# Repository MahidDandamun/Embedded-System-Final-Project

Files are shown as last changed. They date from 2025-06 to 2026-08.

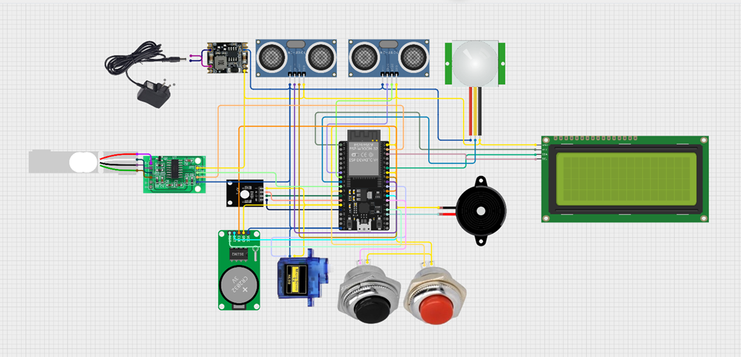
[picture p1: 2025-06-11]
docs/images/interfacing-diagram.png

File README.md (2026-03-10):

# Automated Pet Feeder System

An open-source, IoT-enabled automated pet feeder built with ESP32. Schedule feedings, monitor your pet's eating habits in real-time, and control everything from your phone.

<!-- ![Pet Feeder Hero](docs/images/hero.png) -->

## Features

- **Scheduled Auto-Feeding** — 4 configurable daily feeding times
- **Manual Feed** — Physical button or remote trigger from mobile app
- **Food Level Monitoring** — Ultrasonic sensor detects container level (FULL / HALF / EMPTY)
- **Bowl Weight Tracking** — HX711 load cell measures food in the bowl
- **Pet Detection** — PIR motion sensor detects animal presence
- **Mobile App Control** — React Native app connects via Bluetooth (BLE)
- **Cloud Telemetry** — Azure IoT Hub (MQTT) + REST API for data logging
- **Web Flasher** — Flash firmware from your browser via USB — no IDE needed
- **Status Display** — 16x2 LCD + RGB LED + buzzer feedback
- **Safety Limits** — Daily max (200g), minimum interval (5 min), bowl-full detection

## Repository Structure

```
├── firmware/               # ESP32 firmware (PlatformIO / C++)
│   ├── include/            #   Header files + config
│   ├── src/                #   Source files
│   ├── test/               #   Calibration test
│   └── platformio.ini
├── PCB/                    # KiCad PCB design for breakout board
├── 3D-MODEL/               # Fusion 360 housing + component mounts
├── docs/                   # Specs for mobile app & web flasher
│   ├── MOBILE_APP_SPEC.md  #   React Native mobile app spec
│   └── WEB_FLASHER_SPEC.md #   Next.js web flasher spec
├── .agents/                # AI agent rules, workflows, context
└── README.md               # You are here
```

### Companion Repositories (Separate)

| Repo | Tech Stack | Purpose |
|---|---|---|
| `petfeeder-mobile` | React Native (Expo) + TypeScript | Mobile app — BLE control, dashboard, history |
| `petfeeder-web` | Next.js + Web Serial API | Browser-based firmware flasher & calibration |

## Hardware Requirements

| Component | Model | Qty |
|---|---|-----|
| Microcontroller | ESP32 DevKit C | 1 |
| Ultrasonic Sensor | HC-SR04 | 1 |
| Load Cell + Amplifier | 5kg load cell + HX711 | 1 |
| PIR Motion Sensor | Generic | 1 |
| Servo Motor | SG90 or MG90S | 1 |
| LCD Display | 16x2 I2C (address 0x27) | 1 |
| RTC Module | DS1302 | 1 |
| RGB LED | Common cathode | 1 |
| Active Buzzer | 5V | 1 |
| Push Buttons | IP65 12mm momentary (x2) | 2 |
| Power Supply | 5V 2A, 5.5x2.1mm barrel jack | 1 |
| Rocker Switch | SPST | 1 |
| Custom PCB | See `PCB/` directory | 1 |
| 3D-Printed Housing | See `3D-MODEL/` directory | 1 |

## Quick Start

### 1. Clone

```bash
git clone https://github.com/MahidDandamun/Embedded-System-Final-Project.git
cd Embedded-System-Final-Project
```

### 2. Configure Secrets

```bash
cd firmware
cp include/secrets.h.template include/secrets.h
```

Edit `firmware/include/secrets.h` with your credentials:

```c
#define ENV_WIFI_SSID       "YourWiFi"
#define ENV_WIFI_PASSWORD   "YourPassword"
#define ENV_MQTT_SERVER     "your-hub.azure-devices.net"
#define ENV_MQTT_PORT       8883
#define ENV_DEVICE_ID       "petfeeder"
#define ENV_SAS_TOKEN       "SharedAccessSignature sr=..."
#define ENV_MQTT_USERNAME   "your-hub.azure-devices.net/petfeeder/?api-version=2021-04-12"
#define ENV_DATABASE_ENDPOINT "https://your-api.azurewebsites.net/api/devices/status"
```

> **Never commit `secrets.h`** — it's in `.gitignore`.

### 3. Build & Flash

```bash
# Install PlatformIO CLI
pip install platformio

# Build
pio run

# Upload to ESP32
pio run -t upload

# Monitor serial output
pio device monitor
```

### 4. Calibrate Load Cell

```bash
# Upload calibration firmware
pio test -e esp32dev -f test_calibration
```

Follow the serial prompts to find your `CALIBRATION_FACTOR`, then update it in `firmware/include/config.h`.

### 5. Assemble Hardware

1. Print the housing from `3D-MODEL/` (see [3D-MODEL/README.md](3D-MODEL/README.md))
2. Solder or order the PCB from `PCB/` (see [PCB/README.md](PCB/README.md))
3. Wire everything per the [pin mapping](firmware/README.md#pin-mapping-pcb-v2)
4. Power on and verify via serial monitor

## Architecture

```
┌─────────────┐     BLE      ┌─────────────┐
│  Mobile App │◄────────────►│    ESP32     │
│ (React Native)             │  Firmware    │
└─────────────┘              │             │
                             │  Sensors:    │
┌─────────────┐    MQTT      │  - Ultrasonic│
│  Azure IoT  │◄────────────►│  - Load Cell │
│    Hub      │              │  - PIR       │
└──────┬──────┘              │  - RTC       │
       │                     │             │
       │ REST                │  Actuators:  │
       ▼                     │  - Servo     │
┌─────────────┐              │  - LCD       │
│  Backend DB │              │  - RGB LED   │
│  (REST API) │              │  - Buzzer    │
└─────────────┘              └──────┬───────┘
                                    │ USB
┌─────────────┐    Web Serial      │
│  Web Flasher│◄───────────────────┘
│  (Next.js)  │
└─────────────┘
```

## Mobile App

The companion mobile app (separate repo) provides:

- **Dashboard** — Real-time sensor data, feeding status, pet detection
- **Feeding History** — Charts and timeline of all feeding events
- **Schedule Control** — Edit feeding times and portion sizes
- **BLE Connection** — Direct Bluetooth communication with the feeder
- **Push Notifications** — Low food alerts, missed feeding warnings

**Tech Stack:** React Native (Expo) + TypeScript + Zustand + react-native-ble-plx

See full spec: [docs/MOBILE_APP_SPEC.md](docs/MOBILE_APP_SPEC.md)

## Web Flasher

A browser-based tool to flash firmware and calibrate sensors — no IDE installation required:

1. Connect ESP32 via USB-C
2. Enter WiFi/cloud credentials in the web form
3. Click "Flash" — firmware uploads directly from Chrome
4. Run guided sensor calibration

**Tech Stack:** Next.js + TypeScript + Web Serial API + esptool-js

See full spec: [docs/WEB_FLASHER_SPEC.md](docs/WEB_FLASHER_SPEC.md)

## Pin Mapping

| Function | GPIO | Notes |
|---|---|---|
| Power Relay | 27 | System power control |
| Button 1 (Refill) | 15 | INPUT_PULLUP |
| Button 2 (Feed) | 0 | INPUT_PULLUP |
| Ultrasonic Trig | 32 | |
| Ultrasonic Echo | 33 | |
| PIR Sensor | 25 | |
| HX711 DOUT | 5 | |
| HX711 SCK | 23 | |
| RGB Red | 13 | |
| RGB Green | 12 | |
| RGB Blue | 14 | |
| Buzzer | 26 | Active buzzer |
| Servo | 4 | SG90/MG90S |
| RTC IO | 16 | DS1302 |
| RTC SCLK | 17 | DS1302 |
| RTC CE | 2 | DS1302 |

## Security Notes

- All credentials are stored in `secrets.h` which is **never committed** to git
- A `secrets.h.template` is provided as reference
- Azure SAS tokens should be rotated regularly
- For production: replace `setInsecure()` with proper TLS certificate pinning
- If you ever accidentally commit secrets: **rotate ALL credentials immediately**

### Regarding Credentials in Git History

The credentials found in older commits have been **revoked and are no longer valid**. The WiFi password, Azure SAS tokens, and API endpoints from the git history are all invalidated. Always generate your own fresh credentials.

## Contributing

1. Fork the repository
2. Create a feature branch (`git checkout -b feat/amazing-feature`)
3. Use conventional commits (`feat:`, `fix:`, `docs:`, `refactor:`)
4. Ensure no secrets are in your commits
5. Open a Pull Request

## License

This project is licensed under the [MIT License](LICENSE).

## Authors

- Irish Micole Cando
- Jelisha Bugnon
- Angela Corpuz
- Mahid Dandamun
- Miguel Alfonso Neri

---

> Built as a final project for Embedded Systems course. Designed to be open-source, educational, and production-ready.

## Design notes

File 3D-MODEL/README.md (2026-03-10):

# 3D Model — Pet Feeder Housing

This directory contains the complete 3D model files for the automated pet feeder enclosure.

## Files

| File | Description |
|---|---|
| `AUTOMATED PET FEEDER SYSTEM 3D MODEL.f3z` | Full Fusion 360 project (editable) |
| `PRAMS 2.0 v3.step` | Complete assembled housing (STEP) |
| `FINAL PROJ v5.step` | Final assembly with all components |
| `Pet bowls v1.step` | Food/water bowl models |
| `microservoAssembly v2.step` | Servo motor mount assembly |
| `ESP32-DevkitC32D v1.step` | ESP32 dev board model |
| `HC-SR04 (1) v1.step` | Ultrasonic sensor mount |
| `LCD WITH IIC v1.step` | LCD display bracket |
| `Led RGB for arduino v1.step` | RGB LED holder |
| `load sensor FHDA v1.step` | Load cell mount |
| `PIR Sensor (1) v1.step` | PIR motion sensor mount |
| `RTC DS1302 real time clock v1.step` | RTC module bracket |
| `DC Power Jack 5.5mm x 2.1mm v1.step` | Power jack cutout |
| `RockerSwitch v1.step` | Power switch mount |
| `STARELO 12mm Momentary Push Button...v1.step` | Button mount |

## Housing Assembly Guide

### What You Need

- 3D printer (FDM, PLA or PETG recommended)
- M3 screws and nuts
- Hot glue gun (for sensor mounts)
- Wire (22 AWG for internal wiring)

### Print Settings

| Parameter | Value |
|---|---|
| Material | PLA or PETG |
| Layer Height | 0.2mm |
| Infill | 20–30% |
| Supports | Yes (for overhangs) |
| Wall Thickness | 1.2mm (3 walls) |

### Assembly Steps

1. **Print all housing parts** — Use the STEP files to slice in your slicer software (Cura, PrusaSlicer, etc.)

2. **Install the load cell** — Mount the load cell under the bowl platform using M3 screws. Run wires through the channel to the electronics bay.

3. **Mount the servo** — Use `microservoAssembly v2.step` as reference. The servo controls the food gate. Secure with provided mounting holes.

4. **Install sensors**
   - **Ultrasonic (HC-SR04):** Mount at the top of the food container, pointing downward
   - **PIR Sensor:** Mount near the bowl at pet height
   - **RGB LED:** Install in the front-facing LED slot

5. **Install electronics**
   - **ESP32:** Snap into the bracket inside the electronics bay
   - **LCD Display:** Slide into the front-facing LCD slot
   - **RTC Module:** Mount near the ESP32
   - **Power Jack & Switch:** Install in the rear panel cutouts

6. **Wire everything** per the pin mapping in [firmware/README.md](../firmware/README.md)

7. **Close the housing** and secure with M3 screws

### System Preview

<!-- Add a screenshot of your 3D model here -->
<!-- ![Pet Feeder 3D Model](images/3d-model-preview.png) -->

> **TODO:** Add photos/screenshots of the assembled 3D model here.

### Tips

- Print the bowl platform in PETG for better food safety
- Use cable management clips inside the housing
- Leave access to the USB port for firmware updates
- The power jack hole fits a standard 5.5mm × 2.1mm barrel connector

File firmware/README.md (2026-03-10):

# Firmware — Automated Pet Feeder (ESP32)

PlatformIO-based firmware for the ESP32 pet feeder system.

## Features

- Scheduled auto-feeding (4 times/day, configurable)
- Manual feed via physical button or mobile app (BLE)
- Ultrasonic food-level sensing
- HX711 load cell for bowl weight
- PIR motion detection (animal presence)
- RGB LED + buzzer status feedback
- Azure IoT Hub telemetry via MQTT
- REST API push to backend database
- BLE interface for mobile app control & live status

## Quick Start

### 1. Install PlatformIO

```bash
pip install platformio
# or install the VS Code PlatformIO extension
```

### 2. Configure Secrets

```bash
cp include/secrets.h.template include/secrets.h
```

Edit `include/secrets.h` with your actual credentials:
- WiFi SSID & password
- Azure IoT Hub connection string
- Backend API endpoint

> **Never commit `secrets.h`** — it's listed in `.gitignore`.

### 3. Build & Upload

```bash
pio run                 # compile
pio run -t upload       # flash to ESP32
pio device monitor      # serial monitor (115200 baud)
```

### 4. Calibration

Run the calibration test to set your load cell factor:

```bash
pio test -e esp32dev -f test_calibration
```

Or upload `test/test_calibration.cpp` as the main sketch, follow the serial prompts, and note the factor. Update `CALIBRATION_FACTOR` in `include/config.h`.

## Pin Mapping (PCB v2)

| Function | GPIO |
|---|---|
| Power Relay | 27 |
| Button 1 | 15 |
| Button 2 | 0 |
| Ultrasonic Trig | 32 |
| Ultrasonic Echo | 33 |
| PIR Sensor | 25 |
| HX711 DOUT | 5 |
| HX711 SCK | 23 |
| RGB Red | 13 |
| RGB Green | 12 |
| RGB Blue | 14 |
| Buzzer | 26 |
| Servo | 4 |
| RTC IO | 16 |
| RTC SCLK | 17 |
| RTC CE | 2 |

## Architecture

```
firmware/
├── include/
│   ├── config.h              # All pin/timing/threshold config + structs
│   ├── secrets.h.template    # Template for credentials
│   ├── globals.h             # Extern declarations
│   ├── system_init.h
│   ├── sensor_manager.h
│   ├── feeding_control.h
│   ├── button_handler.h
│   ├── display_manager.h
│   ├── time_manager.h
│   ├── network_manager.h
│   ├── ble_manager.h         # BLE for mobile app
│   └── load_cell.h
├── src/
│   ├── main.cpp              # Setup + main loop
│   ├── globals.cpp
│   ├── system_init.cpp
│   ├── sensor_manager.cpp
│   ├── feeding_control.cpp
│   ├── button_handler.cpp
│   ├── display_manager.cpp
│   ├── time_manager.cpp
│   ├── network_manager.cpp   # MQTT + HTTP
│   ├── ble_manager.cpp       # BLE service
│   └── load_cell.cpp
├── test/
│   └── test_calibration.cpp  # Load cell calibration
└── platformio.ini
```

## BLE Protocol (for Mobile App)

| Characteristic | UUID | Direction | Format |
|---|---|---|---|
| Command | `beb5483e-...` | Write | `{"cmd":"feed"}` or `{"cmd":"refill"}` or `{"cmd":"tare"}` |
| Status | `a3c87500-...` | Notify | JSON with all sensor/state data |

The mobile app connects via BLE, sends commands, and receives real-time status updates every 2 seconds.

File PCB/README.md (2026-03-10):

# PCB — Pet Feeder Breakout Board

KiCad PCB design for the ESP32 pet feeder breakout/carrier board.

## Files

| File | Description |
|---|---|
| `FINAL PROJ.kicad_sch` | Schematic |
| `FINAL PROJ.kicad_pcb` | PCB layout |
| `FINAL PROJ.kicad_pro` | KiCad project |
| `FINAL PROJ.step` | 3D model of PCB |
| `freerouting.dsn` | Auto-routing export |
| `config.h` | Pin mapping reference (mirrors firmware config) |

## Features

- ESP32 DevKit C socket
- Breakout headers for all sensors (HC-SR04, PIR, HX711, DS1302)
- Servo connector (5V + signal)
- I2C header for LCD
- RGB LED + buzzer outputs
- 5V barrel jack power input with rocker switch
- Dual push-button inputs

## Opening the Design

1. Install [KiCad](https://www.kicad.org/) (v7+ recommended)
2. Open `FINAL PROJ.kicad_pro`
3. Schematic → `FINAL PROJ.kicad_sch`
4. PCB Layout → `FINAL PROJ.kicad_pcb`

## Manufacturing

Export Gerbers from KiCad and upload to your preferred PCB fab (JLCPCB, PCBWay, OSH Park, etc.).

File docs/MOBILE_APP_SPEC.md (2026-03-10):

# Mobile App — Pet Feeder Companion (Separate Repository)

> **Repository:** Create as `petfeeder-mobile` (separate repo)

## Tech Stack (Production-Grade, In-Demand)

| Layer | Technology | Why |
|---|---|-----|
| **Framework** | React Native + Expo (SDK 52+) | Cross-platform iOS/Android, massive ecosystem, most in-demand mobile framework |
| **Language** | TypeScript | Type safety, better DX, industry standard |
| **Navigation** | Expo Router (file-based) | Modern, Next.js-style routing for RN |
| **State Management** | Zustand | Lightweight, scalable, minimal boilerplate |
| **BLE Communication** | react-native-ble-plx | Best-maintained BLE library for React Native |
| **Cloud/API** | Azure IoT Hub SDK or REST | Match firmware's Azure backend |
| **Real-time** | Azure SignalR or WebSocket | Live dashboard updates |
| **Charts** | Victory Native or react-native-chart-kit | Historical data visualization |
| **UI Library** | Tamagui or NativeWind (Tailwind) | Production-level, performant styling |
| **Auth** | Clerk or Supabase Auth | Modern auth with social login |
| **Database** | Supabase (PostgreSQL) or Azure Cosmos DB | Historical data storage |
| **Push Notifications** | Expo Notifications | Feeding alerts, low-food warnings |

## Architecture

```
petfeeder-mobile/
├── app/                        # Expo Router screens
│   ├── (tabs)/
│   │   ├── index.tsx           # Dashboard (home)
│   │   ├── history.tsx         # Feeding history
│   │   ├── schedule.tsx        # Feeding schedule management
│   │   ├── settings.tsx        # Device & app settings
│   │   └── _layout.tsx         # Tab navigation layout
│   ├── device/
│   │   ├── connect.tsx         # BLE device scanning & pairing
│   │   ├── calibrate.tsx       # Load cell calibration wizard
│   │   └── [id].tsx            # Individual device detail
│   ├── auth/
│   │   ├── login.tsx
│   │   └── register.tsx
│   └── _layout.tsx             # Root layout
├── components/
│   ├── ui/                     # Reusable UI components
│   │   ├── Card.tsx
│   │   ├── Button.tsx
│   │   ├── Badge.tsx
│   │   └── Chart.tsx
│   ├── dashboard/
│   │   ├── FoodLevelGauge.tsx
│   │   ├── BowlWeightCard.tsx
│   │   ├── FeedingStatusCard.tsx
│   │   ├── MotionIndicator.tsx
│   │   └── QuickFeedButton.tsx
│   └── device/
│       ├── BLEScanner.tsx
│       └── DeviceCard.tsx
├── hooks/
│   ├── useBLE.ts               # BLE connection management
│   ├── useDevice.ts            # Device state from BLE/cloud
│   ├── useFeedingHistory.ts    # Historical data queries
│   └── useRealTimeData.ts      # Live sensor data
├── stores/
│   ├── deviceStore.ts          # Zustand store for device state
│   ├── authStore.ts
│   └── settingsStore.ts
├── services/
│   ├── ble/
│   │   ├── bleService.ts       # BLE connection & communication
│   │   ├── bleProtocol.ts      # Command/status JSON protocol
│   │   └── bleConstants.ts     # UUIDs matching firmware
│   ├── api/
│   │   ├── apiClient.ts        # REST API client
│   │   ├── feedingApi.ts
│   │   └── deviceApi.ts
│   └── notifications/
│       └── pushService.ts
├── utils/
│   ├── formatters.ts
│   └── constants.ts
├── types/
│   ├── device.ts
│   ├── feeding.ts
│   └── sensor.ts
├── assets/
├── app.json
├── package.json
└── tsconfig.json
```

## Key Screens

### 1. Dashboard
- **Real-time food level** — gauge/progress bar (FULL/HALF/EMPTY)
- **Bowl weight** — live grams display
- **Next feeding** — countdown timer
- **Pet detection** — motion indicator
- **Quick Feed** — one-tap manual dispense
- **Connection status** — BLE/WiFi/MQTT indicators
- **Daily summary** — grams dispensed today

### 2. Feeding History
- **Timeline view** — all feeding events (auto + manual)
- **Daily/weekly/monthly charts** — consumption trends
- **Export** — CSV download for vet records
- **Filters** — by date range, feeding type

### 3. Schedule Management
- **Edit feeding times** — add/remove/modify schedule
- **Portion size** — adjust grams per feeding
- **Daily limit** — set maximum daily grams
- **Toggle auto-feeding** — enable/disable

### 4. Device Settings
- **BLE pairing** — scan and connect to feeder
- **WiFi configuration** — update WiFi credentials via BLE
- **Calibration** — guided load cell calibration
- **Firmware info** — version, uptime, diagnostics
- **Notifications** — configure alerts (low food, missed feeding, etc.)

## BLE Protocol

The app communicates with ESP32 via BLE using JSON:

**Send commands:**
```json
{"cmd": "feed"}
{"cmd": "refill"}
{"cmd": "tare"}
{"cmd": "schedule", "times": [480, 720, 1080, 1320]}
{"cmd": "wifi", "ssid": "...", "password": "..."}
```

**Receive status (every 2s via BLE notify):**
```json
{
  "food": "FULL",
  "bowl": "PARTIAL",
  "weight": 85.5,
  "distance": 5.2,
  "dispensing": false,
  "refill": false,
  "dailyFood": 75.0,
  "motion": true,
  "status": "Ready to feed",
  "wifi": true,
  "mqtt": true,
  "time": "14:30:00",
  "nextFeed": "18:00:00"
}
```

## Getting Started

```bash
# Create the repo
npx create-expo-app petfeeder-mobile --template tabs
cd petfeeder-mobile

# Install core dependencies
npx expo install react-native-ble-plx
npm install zustand
npm install @tamagui/core tamagui
npm install victory-native

# Development
npx expo start

# Build
eas build --platform all
```

## UI/UX Guidelines

- **Design System:** Use consistent spacing (4px grid), rounded corners, soft shadows
- **Colors:** Green (full), Blue (half), Red (empty), Purple (dispensing), Yellow (refill)
- **Dark Mode:** Support system theme preference
- **Haptics:** Tap feedback on buttons
- **Animations:** Smooth transitions for gauge values, card reveals
- **Accessibility:** Screen reader labels, minimum touch targets (44×44pt)
- **Offline Mode:** Cache last-known device state when BLE disconnects

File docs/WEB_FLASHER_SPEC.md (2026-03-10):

# Web Flasher & Calibration Tool (Separate Repository)

> **Repository:** Create as `petfeeder-web` (separate repo)

## Overview

A web application that lets users:
1. **Select a project/firmware** from available embedded firmware variants
2. **Flash firmware** directly to their ESP32 via USB (Web Serial API)
3. **Calibrate sensors** (load cell, ultrasonic) through a guided wizard
4. **Configure WiFi/cloud credentials** before flashing

No desktop software required — works entirely in the browser via USB-C/USB connection.

## Tech Stack

| Layer | Technology | Why |
|---|---|-----|
| **Framework** | Next.js 15 (App Router) | SEO, SSR, best React framework |
| **Language** | TypeScript | Type safety |
| **Styling** | Tailwind CSS + shadcn/ui | Production-level components |
| **Firmware Flashing** | Web Serial API + esptool-js | Flash ESP32 from browser |
| **State** | Zustand | Simple, scalable |
| **Database** | Supabase or Vercel Postgres | Store firmware binaries, user configs |
| **Auth** | Clerk or NextAuth.js | User accounts |
| **Hosting** | Vercel | Zero-config deployment |

## Architecture

```
petfeeder-web/
├── app/
│   ├── page.tsx                  # Landing page
│   ├── projects/
│   │   ├── page.tsx              # Browse available firmware projects
│   │   └── [slug]/
│   │       ├── page.tsx          # Project detail + flash button
│   │       ├── flash/
│   │       │   └── page.tsx      # Flashing wizard
│   │       └── calibrate/
│   │           └── page.tsx      # Calibration wizard
│   ├── dashboard/
│   │   └── page.tsx              # User's devices & history
│   └── layout.tsx
├── components/
│   ├── ui/                       # shadcn components
│   ├── flash/
│   │   ├── SerialConnect.tsx     # USB connection prompt
│   │   ├── FlashProgress.tsx     # Progress bar during flash
│   │   ├── FirmwareSelector.tsx  # Choose firmware variant
│   │   └── CredentialForm.tsx    # WiFi/API config before flash
│   ├── calibrate/
│   │   ├── LoadCellWizard.tsx    # Step-by-step calibration
│   │   ├── UltrasonicWizard.tsx
│   │   └── SerialMonitor.tsx     # Live serial output
│   └── projects/
│       ├── ProjectCard.tsx
│       └── ProjectGrid.tsx
├── lib/
│   ├── serial/
│   │   ├── serialService.ts      # Web Serial API wrapper
│   │   ├── espFlasher.ts         # esptool-js integration
│   │   └── serialMonitor.ts      # Read serial output
│   ├── firmware/
│   │   ├── firmwareBuilder.ts    # Inject credentials into firmware
│   │   └── firmwareStore.ts      # Fetch firmware binaries
│   └── supabase/
│       └── client.ts
├── public/
│   └── firmware/                  # Pre-compiled firmware binaries
│       ├── petfeeder-v2.0.0.bin
│       └── manifest.json
├── package.json
├── next.config.ts
└── tailwind.config.ts
```

## User Flow

### Flash Firmware
```
1. User visits /projects and selects "Pet Feeder"
2. Clicks "Flash to Device"
3. Enters WiFi SSID, password, Azure IoT credentials
4. Connects ESP32 via USB-C cable
5. Browser prompts for serial port access
6. Credentials are injected into firmware binary
7. Firmware is flashed to ESP32 (progress bar)
8. Device reboots and connects to WiFi
9. Success screen with next steps
```

### Calibrate Sensors
```
1. User visits /projects/pet-feeder/calibrate
2. Connects ESP32 via USB
3. Guided wizard:
   a. "Remove all weight from scale" → Tare
   b. "Place 100g weight" → Read
   c. Shows calibration factor
   d. "Verify: place known weight" → Confirm
4. Factor is saved to device EEPROM
```

## Web Serial API Requirements

- **Browser:** Chrome 89+, Edge 89+, Opera 76+ (no Firefox/Safari)
- **Connection:** USB-C or USB-Micro to ESP32
- **Baud Rate:** 115200
- **Protocol:** The web app sends serial commands and reads responses

### Serial Commands (Calibration Mode)
```
> TARE
< OK:TARED
> CALIBRATE:100.0
< OK:FACTOR:49400
> VERIFY
< OK:WEIGHT:99.8
> SAVE
< OK:SAVED
```

## Key Features

### Firmware Project Browser
- Grid of available firmware projects (Pet Feeder, future projects)
- Version history
- Hardware requirements list
- Difficulty rating

### Flash Wizard
- Step-by-step with clear instructions
- Auto-detect ESP32 board type
- Credential injection (compile-time or runtime EEPROM write)
- Progress bar with stage labels (Connecting → Erasing → Writing → Verifying)
- Error recovery (retry, reset instructions)

### Calibration Tool
- Live serial monitor output
- Interactive guided steps with illustrations
- Save calibration to device
- Export calibration report

### Dashboard (Logged-in Users)
- List of flashed devices
- Firmware update notifications
- Configuration backup/restore

## Getting Started

```bash
# Create the repo
npx create-next-app@latest petfeeder-web --typescript --tailwind --app
cd petfeeder-web

# Install dependencies
npm install esptool-js
npx shadcn@latest init
npm install zustand

# Development
npm run dev

# Deploy
vercel deploy
```

## Browser Compatibility Note

Web Serial API is only available in Chromium-based browsers. Display a compatibility notice for unsupported browsers with a link to Chrome download.

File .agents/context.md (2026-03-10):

# Agent Context — Project Overview

## What Is This?

An open-source **Automated Pet Feeder System** built as an embedded systems project. It consists of multiple repositories and components:

### This Repository (Main)
- **firmware/** — ESP32 C++ firmware (PlatformIO)
- **PCB/** — KiCad breakout board design
- **3D-MODEL/** — Fusion 360 housing and component mounts
- **docs/** — Additional documentation

### Companion Repositories (Separate)
- **petfeeder-mobile** — React Native (Expo) mobile app
- **petfeeder-web** — Next.js web flasher + calibration tool

## Hardware Components

| Component | Model | Purpose |
|---|---|---|
| Microcontroller | ESP32 DevKit C | Main controller, WiFi + BLE |
| Ultrasonic Sensor | HC-SR04 | Food level detection |
| Load Cell + HX711 | Generic 5kg | Bowl weight measurement |
| PIR Sensor | Generic | Animal presence detection |
| Servo Motor | SG90 / MG90S | Food gate actuator |
| LCD Display | 16×2 I2C (0x27) | Status display |
| RTC Module | DS1302 | Timekeeping |
| RGB LED | Common cathode | Status indicator |
| Buzzer | Active | Audio feedback |
| Push Buttons | x2 (IP65) | Refill mode + Manual feed |
| Power | 5V 2A barrel jack | System power |

## Communication Channels

1. **BLE** — Mobile app ↔ ESP32 (local, low-latency)
2. **MQTT** — ESP32 → Azure IoT Hub (telemetry + remote commands)
3. **HTTP** — ESP32 → REST API backend (database sync)
4. **Web Serial** — PC ↔ ESP32 (firmware flashing via web app)

## Feeding Schedule

Default: 08:00, 12:00, 18:00, 22:00 — configurable in `config.h`.

- 25g per feeding
- 200g daily max
- 5-minute minimum interval between feedings
- Bowl-full detection prevents over-feeding

## Team

- Irish Micole Cando
- Jelisha Bugnon
- Angela Corpuz
- Mahid Dandamun
- Miguel Alfonso Neri

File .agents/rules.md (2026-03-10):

# Agent Rules — Pet Feeder Project

## Project Context

This is an open-source automated pet feeder system built with:

- **Hardware:** ESP32 (PlatformIO/Arduino framework)
- **Cloud:** Azure IoT Hub (MQTT) + REST API backend
- **Mobile App:** React Native (Expo) — separate repository
- **Web Flasher:** Next.js + Web Serial API — separate repository
- **PCB:** KiCad
- **3D Model:** Fusion 360

## Coding Standards

### C++ (Firmware)

- Use `const char*` over `String` for fixed strings to reduce heap fragmentation
- Use `char[]` in structs, not `String`
- All timing via `millis()` — never use blocking `delay()` in main loop
- Prefix private/static helpers with `static`
- Use `snprintf` over `sprintf` — always pass buffer size
- Use `strncpy` over `strcpy` — always pass size
- No dynamic memory allocation in loop
- Keep ISRs minimal
- Follow the existing module pattern: each feature in its own `.h` + `.cpp` pair

### Secrets & Security

- **NEVER** commit `secrets.h`, `.env`, API keys, tokens, or passwords
- Always load credentials from `secrets.h` which is gitignored
- Use `secrets.h.template` as the checked-in reference
- For production: use proper TLS certificate pinning (not `setInsecure()`)

### Git

- Conventional commits: `feat:`, `fix:`, `refactor:`, `docs:`, `chore:`
- One logical change per commit
- Do not commit build artifacts (`.pio/`, `build/`, `node_modules/`)
- Do not commit IDE configs (`.vscode/` settings that are user-specific)

## Architecture Decisions

1. **BLE for mobile app** — Low-latency local control without requiring WiFi. The mobile app connects directly to the ESP32 over BLE.
2. **MQTT for cloud** — Reliable pub/sub for telemetry and remote commands via Azure IoT Hub.
3. **HTTP POST for DB** — Simple REST fallback for database status updates.
4. **DS1302 RTC** — Keeps feeding schedule accurate even without WiFi.
5. **Modular firmware** — Each subsystem (sensors, feeding, display, network, BLE) is isolated in its own module for testability and readability.

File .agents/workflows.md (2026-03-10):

# Agent Workflows

## Firmware Development Workflow

```
1. Edit code in firmware/src/ and firmware/include/
2. Build: pio run
3. Upload: pio run -t upload
4. Monitor: pio device monitor
5. Test: pio test
```

## Adding a New Sensor

```
1. Create include/new_sensor.h with function declarations
2. Create src/new_sensor.cpp with implementation
3. Add extern globals to include/globals.h if needed
4. Add pin definitions to include/config.h
5. Call init from system_init.cpp
6. Call handler from main.cpp loop
7. Add data fields to SensorData struct in config.h
8. Update BLE status payload in ble_manager.cpp
9. Update MQTT telemetry payload in network_manager.cpp
```

## Adding a New BLE Command

```
1. Add command handler in ble_manager.cpp CmdCallbacks::onWrite()
2. Send JSON from mobile app: {"cmd": "your_command", ...params}
3. Document in firmware/README.md BLE Protocol table
```

## Adding a New MQTT Direct Method

```
1. Add method handler in network_manager.cpp handleDirectMethod()
2. Register in Azure IoT Hub portal
3. Send response on "$iothub/methods/res/{status}/?$rid={rid}"
```

## Calibration Workflow

```
1. Upload test/test_calibration.cpp
2. Follow serial prompts to tare and place known weight
3. Note the CALIBRATION_FACTOR
4. Update CALIBRATION_FACTOR in include/config.h
5. Re-upload main firmware
```

## Secrets Management

```
1. cp include/secrets.h.template include/secrets.h
2. Edit secrets.h with real values
3. NEVER commit secrets.h
4. If accidentally committed: rotate ALL credentials immediately
```

## Release Workflow

```
1. Update FIRMWARE_VERSION in config.h
2. Test all features (feeding, BLE, MQTT, sensors)
3. Run calibration verification
4. Commit with: feat: release v{version}
5. Tag: git tag v{version}
6. Push: git push --tags
```

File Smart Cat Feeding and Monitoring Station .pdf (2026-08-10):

Republic of the Philippines
Polytechnic | University | of | the
Philippines
College of Engineering
Computer Engineering Department

## Embedded Systems

# Smart Cat Feeding and Monitoring Station

### Introduction

a. The Team
BSCOE 4-2 | Group 5
Name | Role
Bugnon, Jelisha Ruth B. | Prototype Designer
Cando, Irish Micole T. | Website Developer
Corpuz, Angela E. | Prototype Designer
Dandamun, Mahid L. | Hardware Engineer
Neri, Miguel Alfonso B. | Prototype Designer
b. Overview of the system

In modern urban lifestyles, many cat owners lead busy schedules that require them to be away from home for extended periods, whether due to work commitments, frequent travel, or other obligations. While cats are often considered low-maintenance pets compared to dogs, they still require regular care, particularly in terms of feeding and health monitoring. The absence of a reliable and consistent feeding routine can negatively affect a cat’s well-being, especially when owners are unable to be present at scheduled mealtimes.

Irregular feeding patterns may lead to a variety of health issues in cats, such as obesity, malnutrition, or gastrointestinal discomfort. These issues are often exacerbated when there is no one available to monitor the pet's behavior or appetite changes, which can be early signs of underlying medical conditions (Gunn-Moore, 2005). Moreover, prolonged solitude without supervision can result in stress and behavioral problems for the cat. For owners, this lack of oversight often results in anxiety and uncertainty about their pet’s condition while they are away.

The Smart Cat Feeding and Monitoring Station is an embedded system designed to provide convenience and assurance for cat owners who are frequently away from home. It automates feeding schedules, monitors food levels, and detects cat presence and feeding behavior. With a combination of sensors, actuators, and a microcontroller, the system ensures timely feeding while tracking essential metrics through a web-based dashboard. This setup not only promotes better cat care but also allows owners to monitor and respond remotely.

c. Objectives and goals of the system

The main objectives of the Smart Cat Feeding and Monitoring Station are as follows:

- To automate cat feeding on a schedule using a servo-controlled dispenser.
- To monitor food intake and cat presence using weight sensors and motion detectors.
- To alert the owner when the cat is not eating, food levels are low, or other abnormal activities are detected.
- To log and display feeding data and cat presence via an intuitive web dashboard.
- To provide manual feed control, both physically through push buttons and remotely through the dashboard.
d. Features of the system

The following are the features implemented into the system, ensuring full delivery of the objectives mentioned beforehand:

- Feeding Detection: Measures weight before and after feeding to log intake.
- Cat Presence Monitoring: Uses PIR sensor to track cat approach and interaction time.
- Real-Time Alerts: Buzzer, RGB LED, and web notifications for low food or missed feeding.
- Web Dashboard Integration: Displays feeding logs, activity data, and manual control options.
- LCD Display: Provides on-device information including food weight and system alerts.
- Scheduled and Manual Feeding: Automated feeding based on real-time clock, with options for physical or remote manual feed override.

### Hardware Requirements

a. List of necessary components needed/used. Discuss briefly each component and its purpose.
Quantity | Component Name | Purpose
1 | ESP32 WROOM 32D (38pin) | Main microcontroller with Wi-Fi/Bluetooth for connectivity and logic control
1 | Ultrasonic Sensor (HC-SR04) | Detects the distance of food level
1 | PCB for power and modules | For power distribution and connection of components
1 | PIR SENSOR | Detects the presence of animal via heat
1 | Load Cell + HX711 Amplifier | Measures the weight of the food bowl to detect feeding
1 | Servo Motor | Dispenses food automatically

1 | Real-Time Clock (RTC) Module | Keeps accurate time for feeding history
1 | Buzzer | Gives sound alerts for low food
1 | RGB LED | Visual indicator for low food
1 | LCD | Displays real-time information such as current food weight/percentage, feeding status, alerts
2 | Momentary Push Button | Buttons for dispensing and refilling of the food tank
1 | Food Bowl | Container where the cat eats; used in conjunction with the load cell to monitor food intake
1 | Food Container | Storage container for cat food; supplies food to the dispensing mechanism
— | Plywood | Used as the primary material for building the casing and structural frame

### Software Requirements

a. Libraries required for the project (if any)
- marcoschwartz/LiquidCrystal_I2C@^1.1.4
- bogde/HX711@^0.7.5
- knolleary/PubSubClient@^2.8
- bblanchon/ArduinoJson@^6.21.3
- madhephaestus/ESP32Servo@^0.13.0
- makuna/RTC@^2.5.0
b. Source Code (C++ program). Please provide a google link of the sketch

GitHub Repository Links for the source codes used in developing the system:

1. Hardware Code: https://github.com/MahidDandamun/Embedded-System-Final-Project.git

### 2. Website Code (Front End): https://github.com/irishmicoletcando/pet-feeder-frontend.git

### 3. Website Code (Back End): https://github.com/irishmicoletcando/pet-feeder-backend.git

### 4. Actual Website: https://pet-feeder-ruddy.vercel.app

### System Design and settings

a. System Architecture/Interfacing diagram of the system

Schematic Diagram

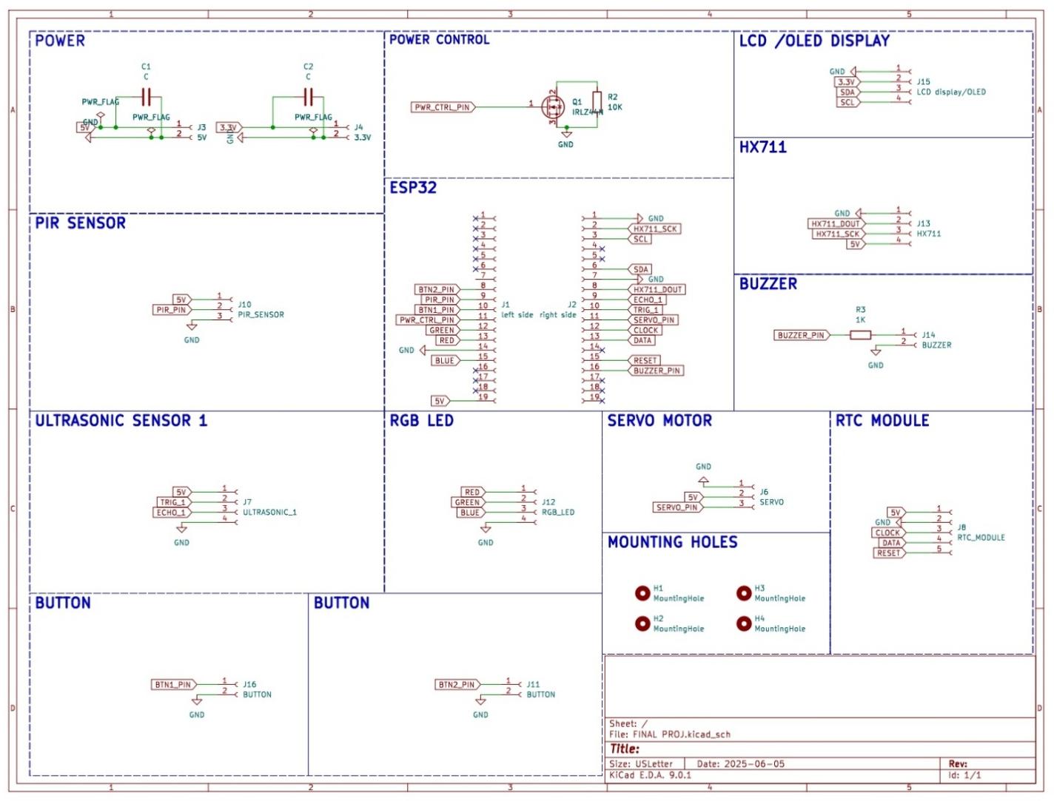
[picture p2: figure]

Interface Diagram

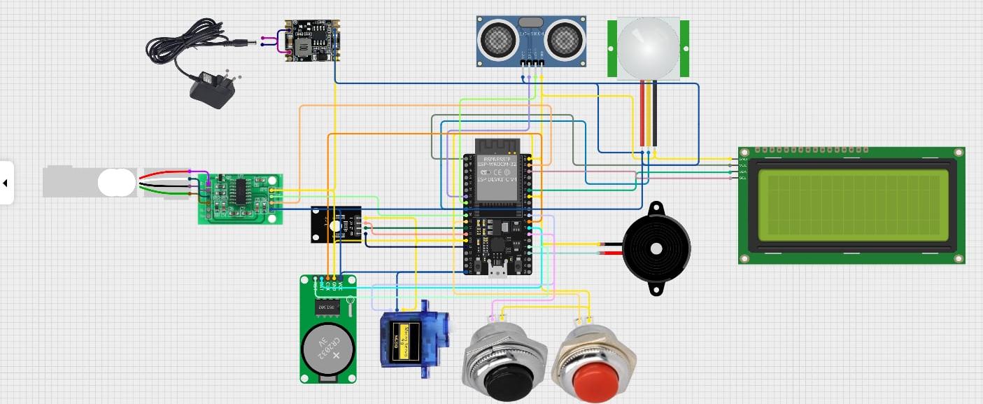
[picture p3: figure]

Current Consumption

Component | Current (mA)
Ultrasonic Sensor | 6
Servo Motor | 500
ESP32 (WiFi) | 400
RGB Module | 20
LCD I2C | 3
PIR Sensor | 3
RTC Module | 0.3
HX711 | 1.6
Buzzer | 30
Buttons (est.) | 1
Total | 964.9

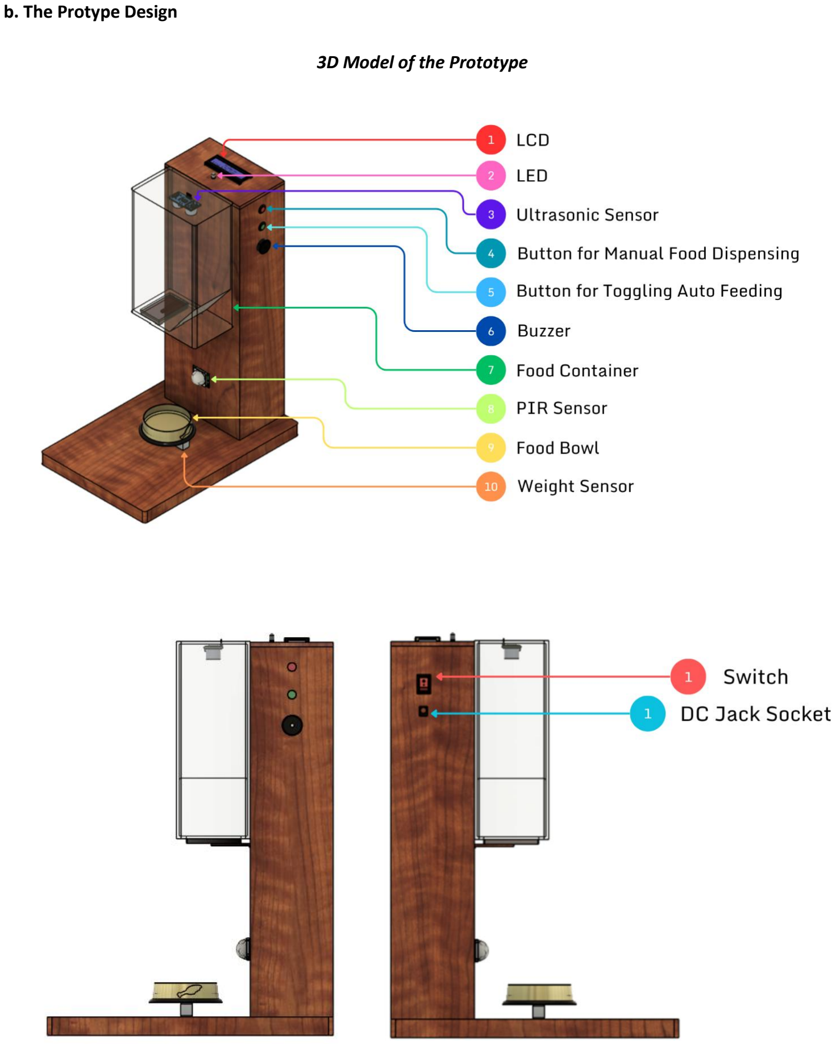
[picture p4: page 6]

b. The Protype Design

3D Model of the Prototype

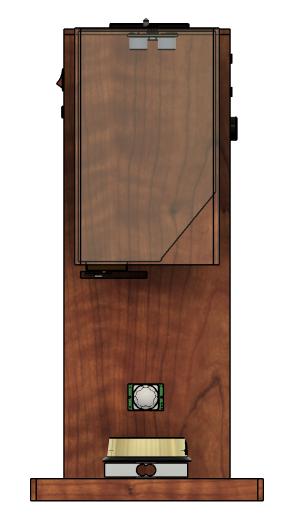
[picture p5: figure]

### Innovation

a. Innovation of the projects
- Cat Presence Detection

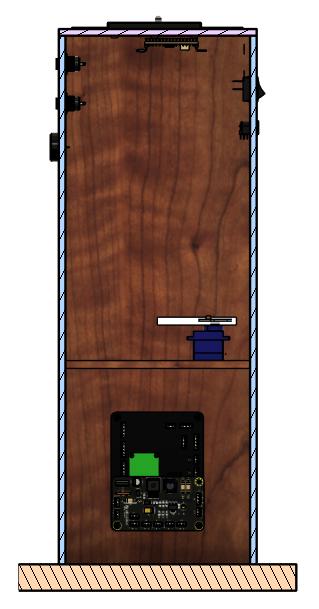
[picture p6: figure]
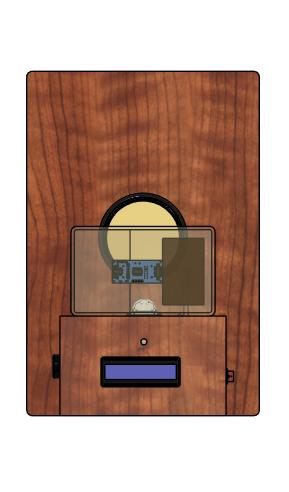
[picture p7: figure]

By integrating a Passive Infrared (PIR) sensor, the system can detect when the cat is near the feeding station. This enables tracking of cat behavior and feeding patterns.

- Website Integration
A custom web dashboard allows cat owners to remotely monitor feeding activity, food levels, and cat presence. It also provides real-time alerts and historical data, offering convenience and peace of mind, especially for owners who are frequently away.
- Manual Override through Button and Web
To increase flexibility, the system supports manual food dispensing both physically via push buttons and remotely through the web interface. This dual-mode override ensures owners can respond to unexpected situations anytime, from anywhere.

### Conclusion

a. Summary of the system

The Smart Cat Feeding and Monitoring System aims to provide convenience for cat owners who are frequently away from home through automated feeding schedules, monitoring cat’s food levels, and detecting cat presence and feeding behavior. Its main features consist of logging feeding intake into the database, real life monitoring of cat presence through PIR sensor, real time alerts for low food level or missed feeding schedule, web dashboard for overview of activity data along with manual control options, an LCD display for providing device information such as food weight and system alerts, and automated or manual feeding based on real time clock.

The Smart Cat Feeding and Monitoring System mainly consists of ESP32 microcontroller for controlling the entire system, PIR sensor for cat presence detection, Ultrasonic Sensor for determining the food level, Load Cell for measuring the weight of food on the bowl, Servo Motor for dispensing the food automatically, and the combination of Buzzer, RGB LED, and LCD for displaying information and sending alert when the food level is low.

To further enhance the system, a PIR sensor was integrated so that the system can detect when the cat is near the system, allowing tracking of cat behavior and its feeding patterns. Website integration was also utilized to further improve as it allows users to remotely monitor any activity and food levels through the dashboard, offering convenience and peace of mind for cat owners. Furthermore, a manual override was also implemented through a physical button and in the web application, allowing manual food dispensing so that users can still respond to unexpected situations anywhere and anytime.

Overall, the system was able to perform its intended functions effectively, dispensing food accurately during user-defined feeding times set through the web application. The integration of the PIR sensor allowed reliable detection of cat presence near the feeding station, enabling monitoring of feeding behavior and interaction patterns. Real-time alerts through the buzzer, RGB LED, and web notifications ensured the user was promptly informed of low food levels or missed feedings, adding an extra layer of reliability. The web dashboard provided a clear and intuitive interface for monitoring system status and feeding logs, while also supporting remote manual control, offering convenience and flexibility. The LCD display on the device ensured that essential information like food weight and system alerts were always visible on-site. Together, these components created a cohesive and responsive system capable of automating cat feeding while maintaining real-time awareness of both food supply and cat activity.

b. Knowledge gained / Lessons learned

Through the Smart Cat Feeding and Monitoring System, we have gained valuable experience in hardware and software integration, resulting in the creation of a cohesive and user-centric IoT solution. We realized the importance of designing systems that prioritize user accessibility, provide clear and timely system feedback, and maintain a high level of reliability, especially in real-world applications where consistency and responsiveness are critical.

The project also taught us how crucial it is to plan for both expected and unexpected user interactions, which led to implementing manual override options both physically and remotely. We learned the significance of real-time data processing and communication between components, especially in synchronizing sensor inputs, actuator responses, and web-based updates. Additionally, working with multiple sensors and modules required us to address challenges in power management, data accuracy, and component compatibility, further strengthening our troubleshooting and system optimization skills.

Furthermore, this project helped us understand how to structure and present data meaningfully through a web dashboard, highlighting the role of user interface design in IoT systems. It also emphasized the need for modular and scalable code, enabling easier maintenance and future enhancements. Overall, this experience not only deepened our technical understanding but also reinforced the value of thoughtful design, thorough testing, and user-focused development in solving everyday challenges faced by cat owners.

c. Future enhancements and areas for improvement

While the Smart Cat Feeding and Monitoring System was able to do its functions along with the enhancements implemented, here are key ideas that will help to maximize the performance of the system:

1. Live Camera Monitoring: Integrate a camera to provide real-time video streaming through the web dashboard, allowing users to visually check on their cat’s behavior and feeding activity remotely.
2. Mobile App Integration: Develop a dedicated mobile application for easier access to system controls, alerts, and real-time monitoring, offering greater convenience compared to a web-only interface.
3. Multi-Pet Support: Use RFID tags or image recognition to identify individual cats, enabling personalized feeding schedules and accurate tracking of food intake per cat.
4. Weather-Resistant Design: Upgrade the casing and structural materials to make the system durable for outdoor use, protecting it from rain, dust, and varying temperatures.
5. AI-Based Feeding Analysis: Introduce machine learning to analyze feeding patterns over time, helping detect irregular behavior or early signs of health issues in cats.

### References and Documentation

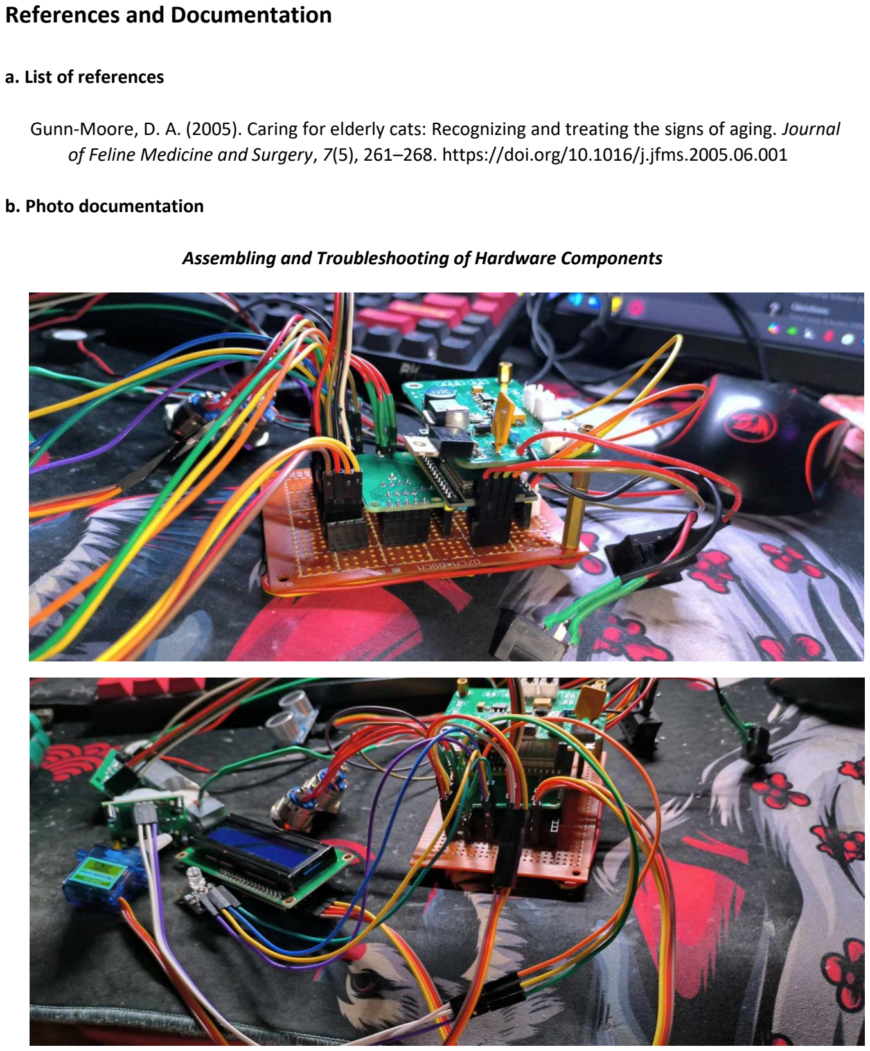
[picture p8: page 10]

a. List of references

Gunn-Moore, D. A. (2005). Caring for elderly cats: Recognizing and treating the signs of aging. Journal of Feline Medicine and Surgery, 7(5), 261–268. https://doi.org/10.1016/j.jfms.2005.06.001

b. Photo documentation

Assembling and Troubleshooting of Hardware Components

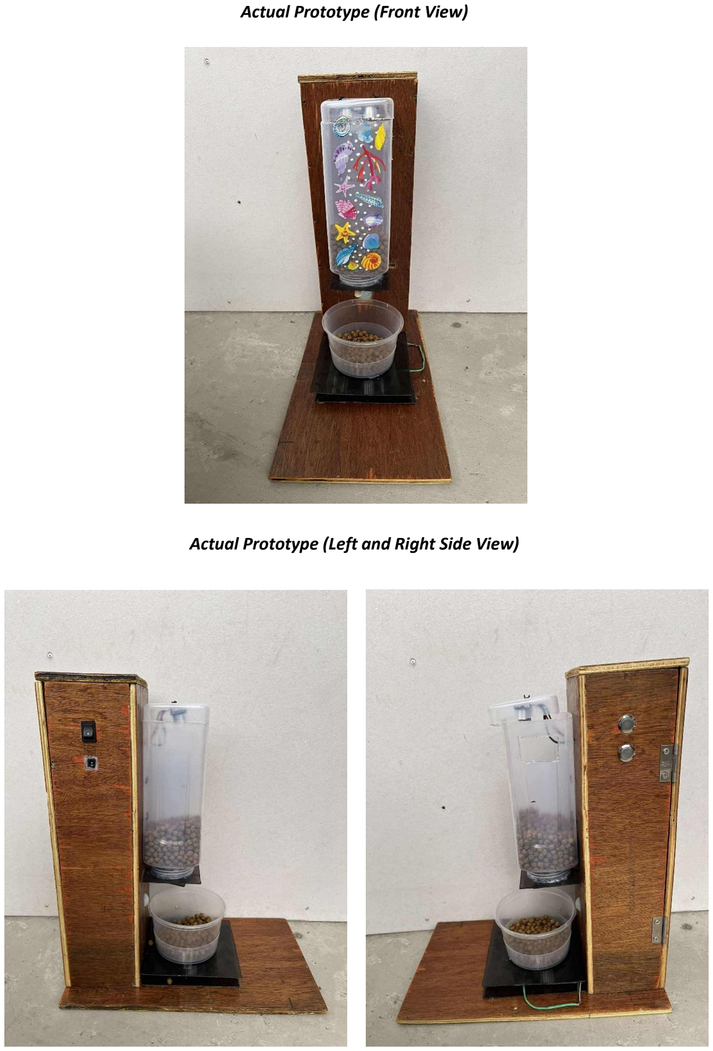
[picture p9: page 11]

Actual Prototype (Front View)

Actual Prototype (Left and Right Side View)

Actual Prototype (Top View)

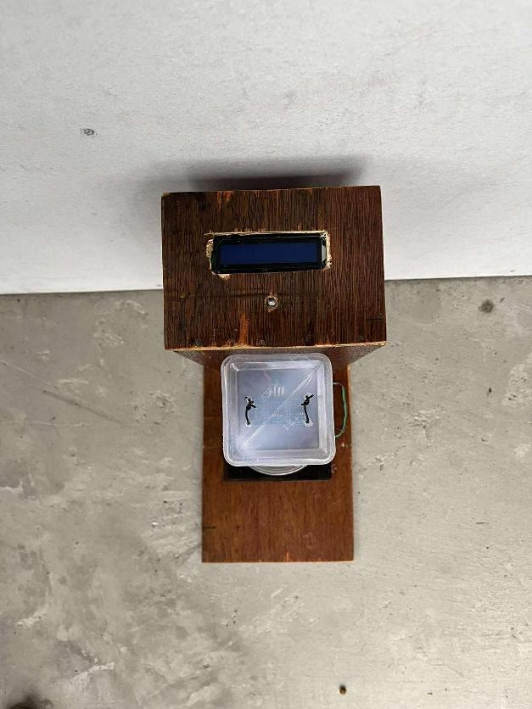
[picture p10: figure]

Actual Prototype (Back View)

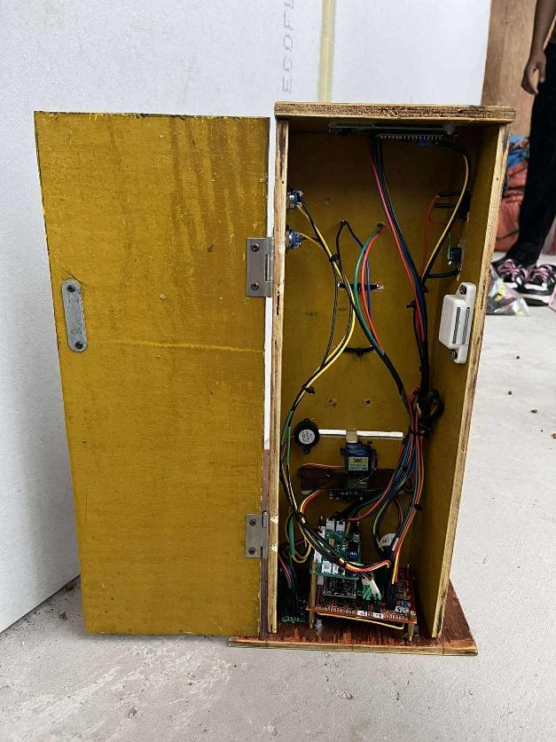
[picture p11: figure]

Close Up View of the Components

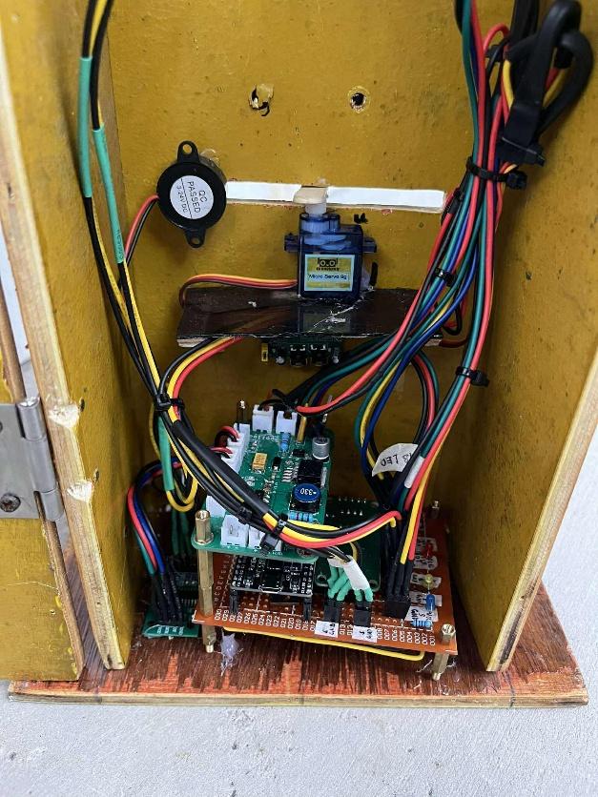
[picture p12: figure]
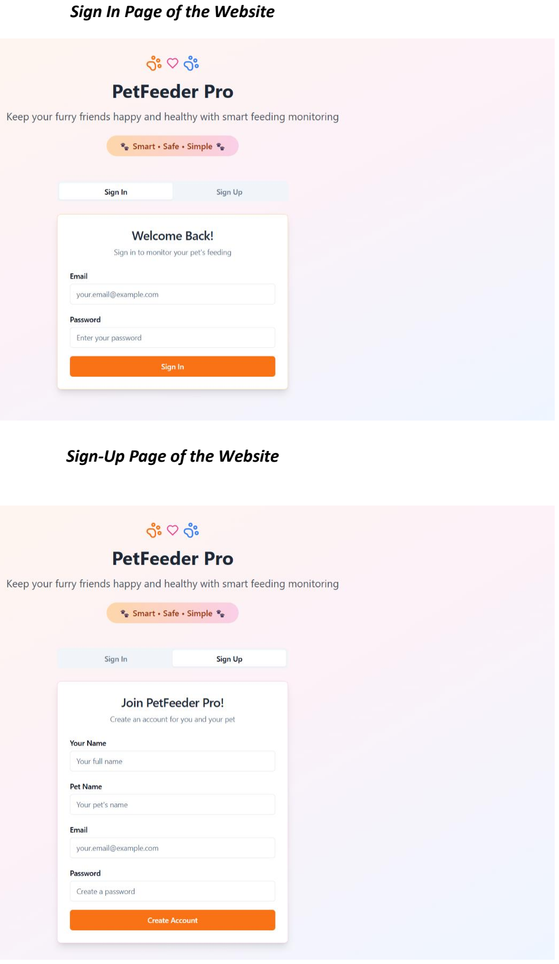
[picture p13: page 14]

Sign In Page of the Website

Sign-Up Page of the Website

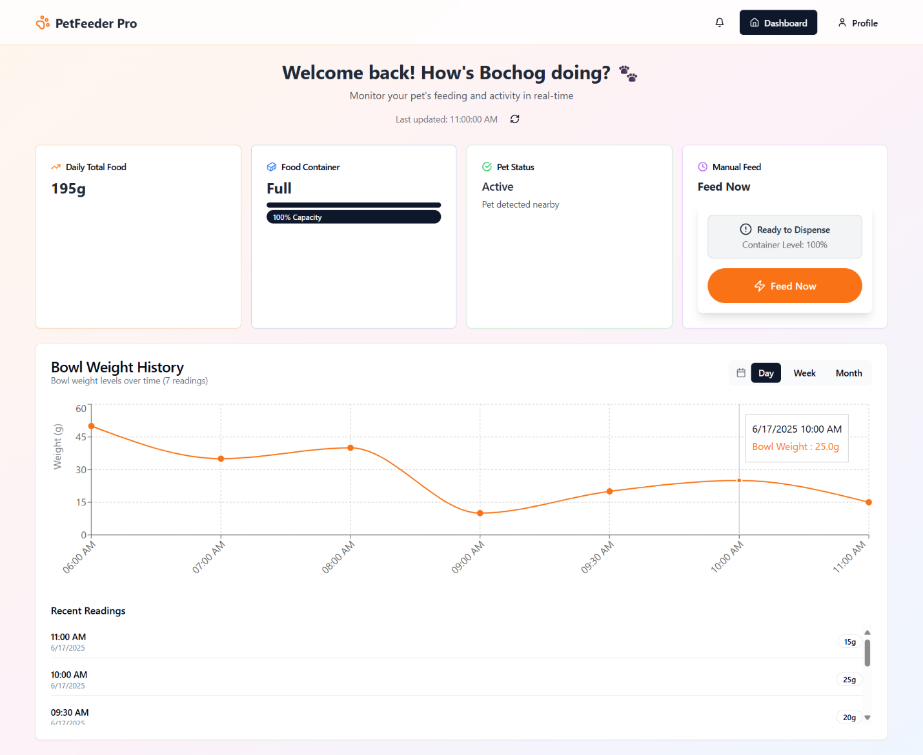
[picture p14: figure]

Dashboard Page of the Website

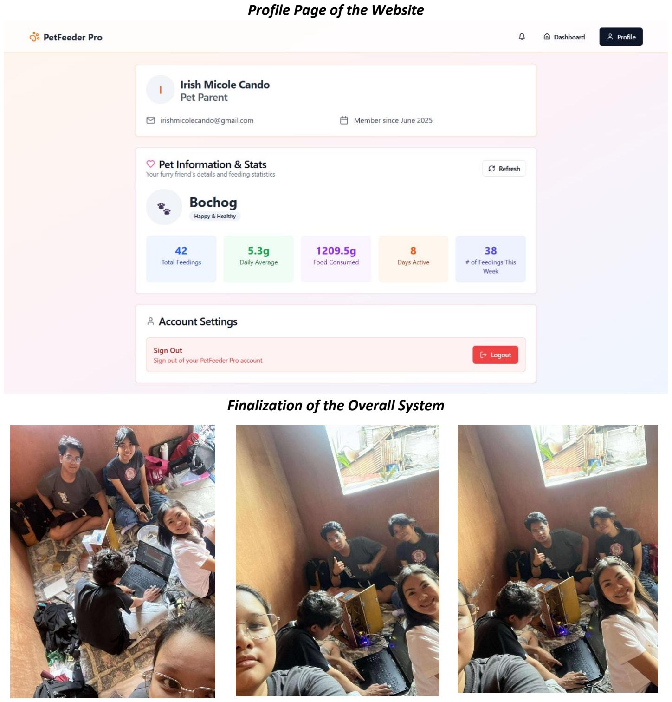
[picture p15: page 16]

Profile Page of the Website

Finalization of the Overall System

Group Photo After Presentation

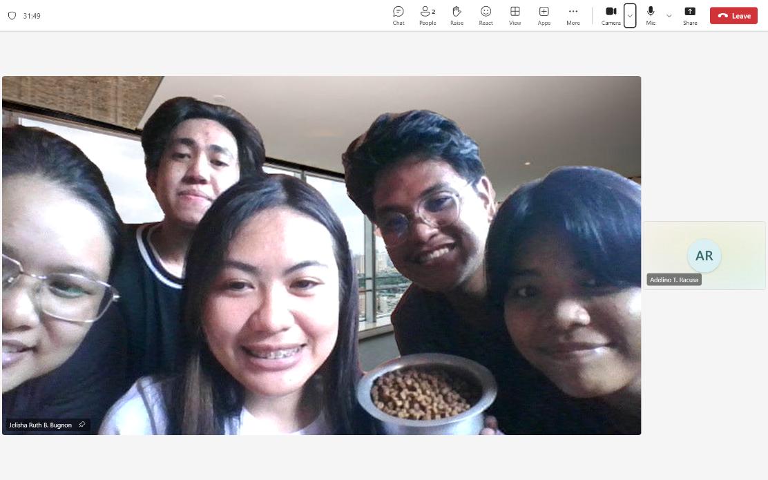
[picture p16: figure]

Final Grade

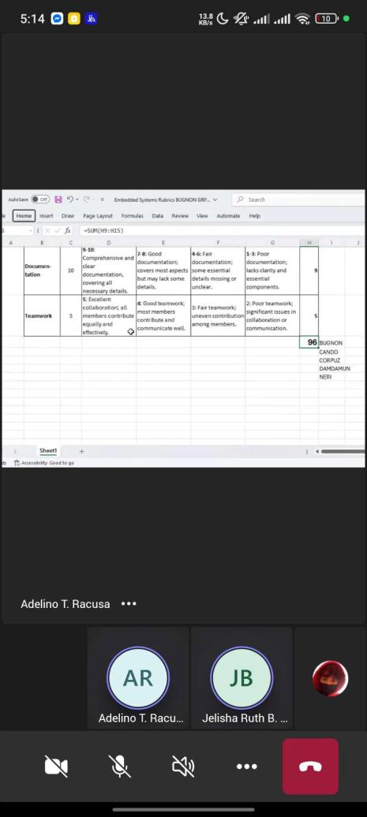
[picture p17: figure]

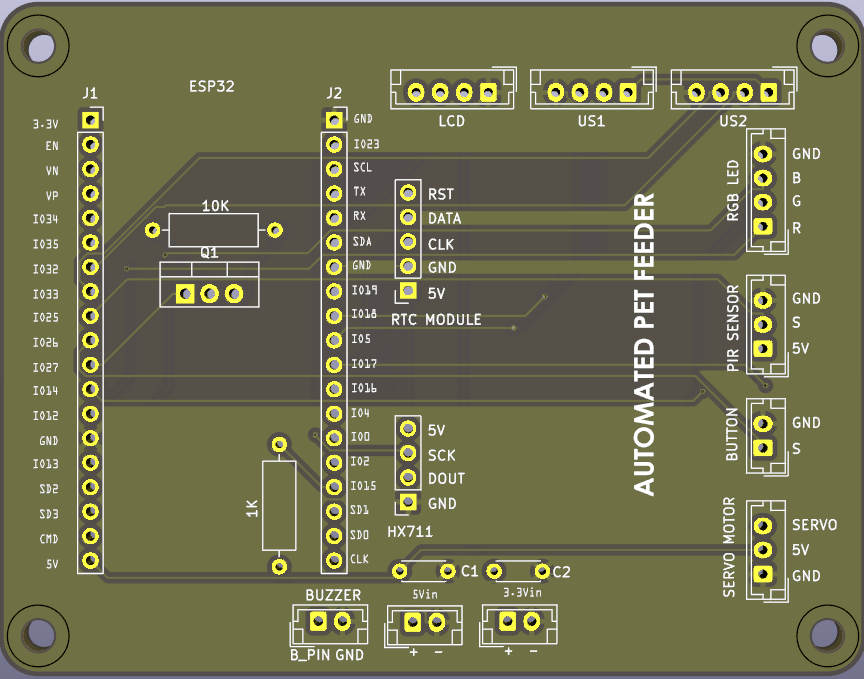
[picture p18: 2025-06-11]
PCB/MAINBOARD-SILKSCREEN.png

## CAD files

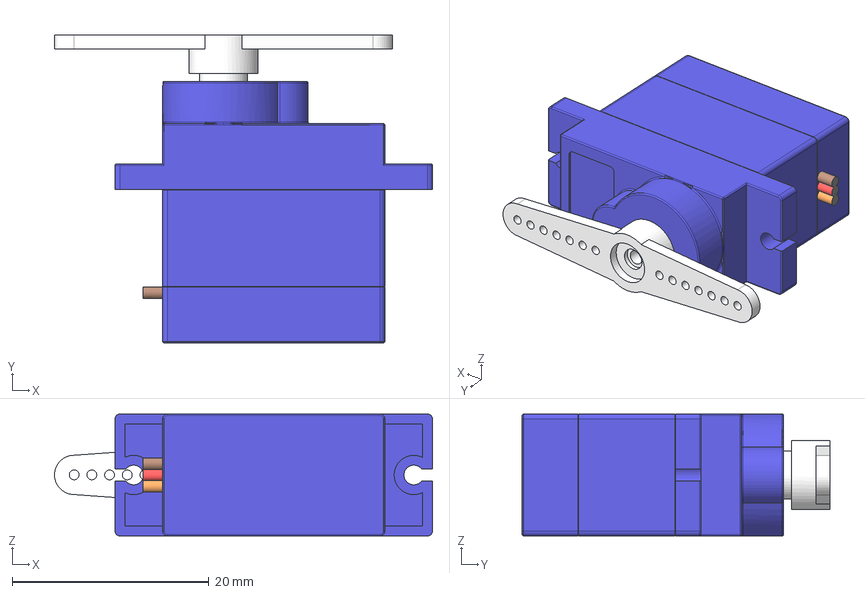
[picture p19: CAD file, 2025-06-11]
3D-MODEL/microservoAssembly v2.step
38.4 x 31.3 x 12.4 mm
microservoSG90
microservoArm_A2

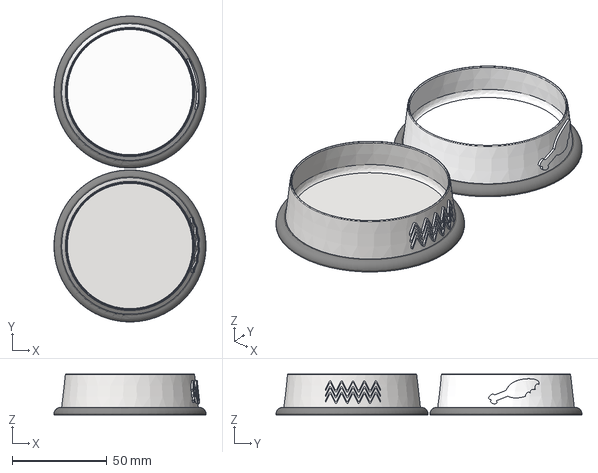
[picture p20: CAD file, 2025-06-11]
3D-MODEL/Pet bowls v1.step
80.0 x 161.0 x 21.5 mm

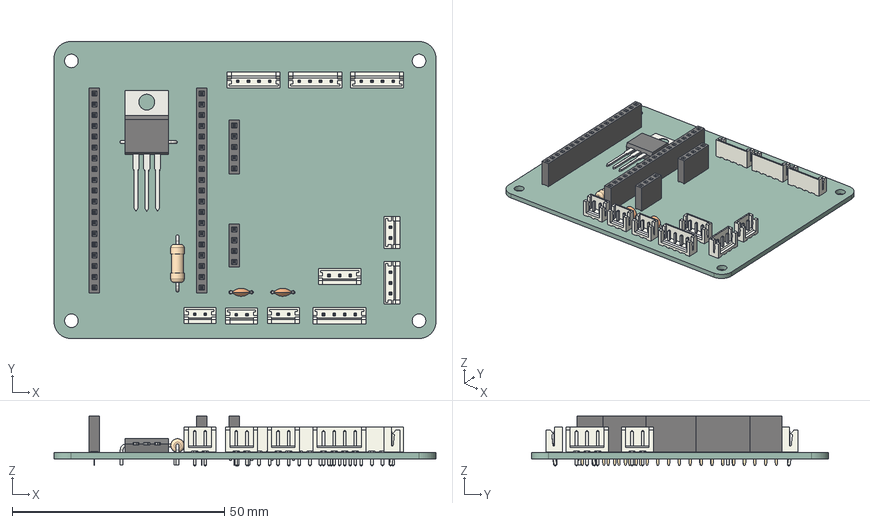
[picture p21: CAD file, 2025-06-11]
PCB/FINAL PROJ.step
90.0 x 70.0 x 11.7 mm
JST_EH_B3B-EH-A_1x03_P2.50mm_Vertical x 2
JST_EH_B2B-EH-A_1x02_P2.50mm_Vertical x 4
TO-220-3_Vertical
R_Axial_DIN0309_L9.0mm_D3.2mm_P12.70mm_Horizontal x 2
PinSocket_1x19_P2.54mm_Vertical x 2
PinSocket_1x04_P2.54mm_Vertical
JST_EH_B4B-EH-A_1x04_P2.50mm_Vertical x 4
C_Disc_D4.3mm_W1.9mm_P5.00mm x 2
PinSocket_1x05_P2.54mm_Vertical
FINAL PROJ_PCB

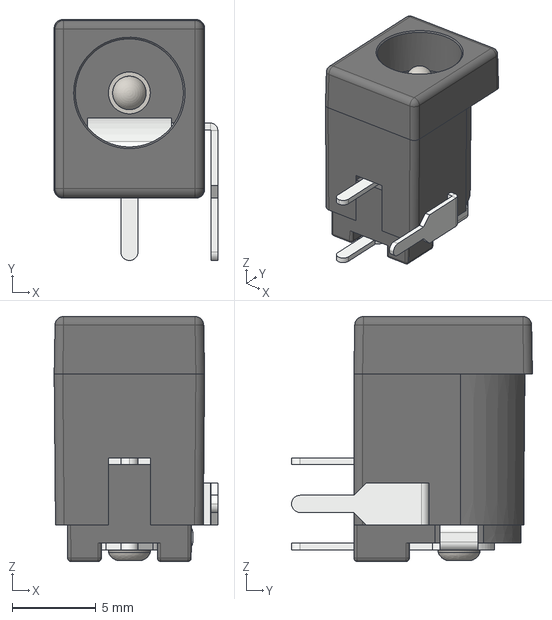
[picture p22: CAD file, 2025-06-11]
3D-MODEL/DC Power Jack 5.5mm x 2.1mm v1.step
9.77 x 14.4 x 14.6 mm

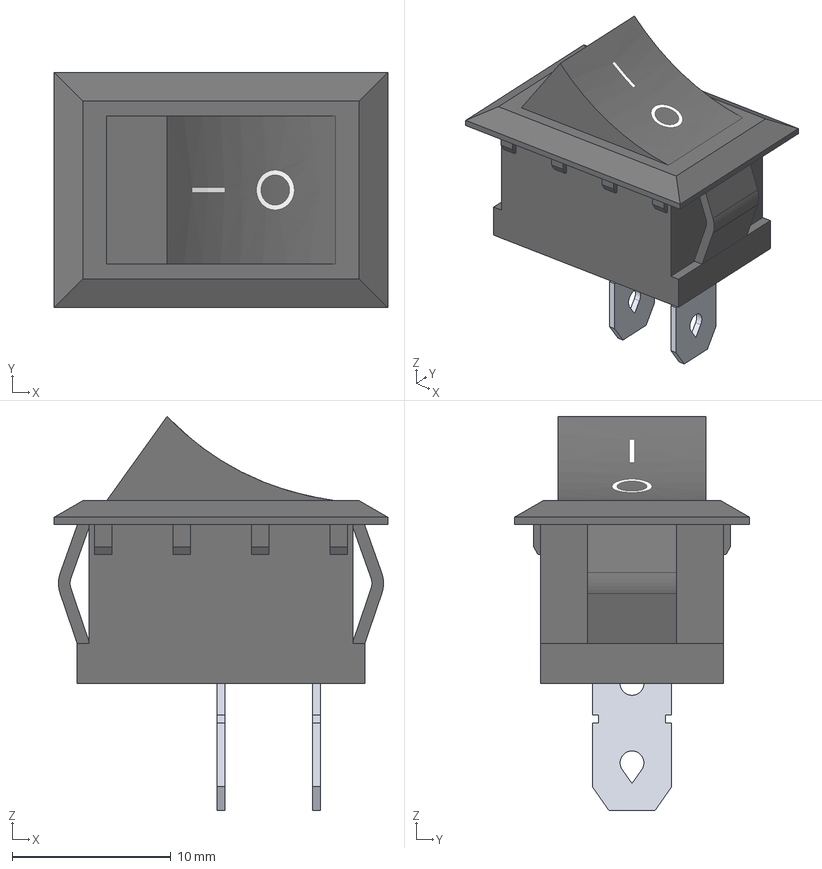
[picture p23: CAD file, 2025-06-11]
3D-MODEL/RockerSwitch v1.step
21.0 x 14.8 x 24.8 mm

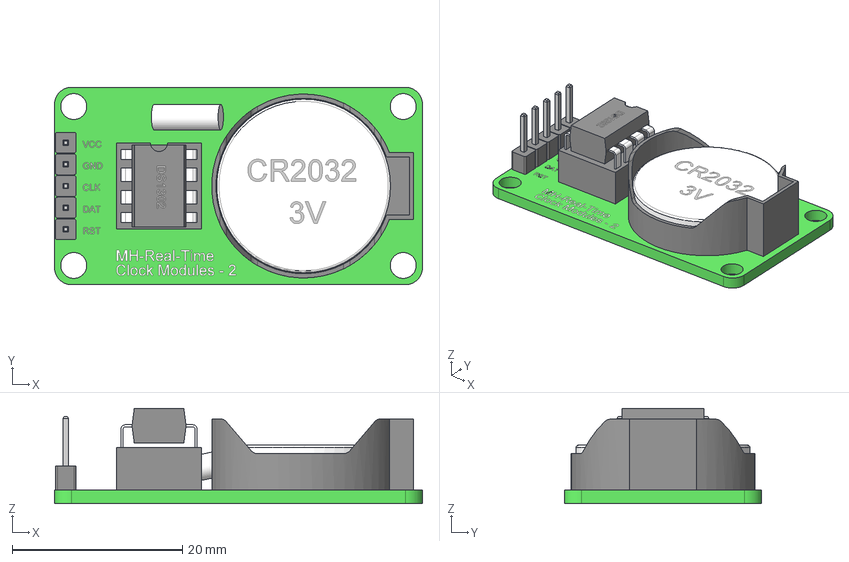
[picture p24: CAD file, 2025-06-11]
3D-MODEL/RTC DS1302 real time clock v1.step
43.2 x 23.2 x 11.2 mm

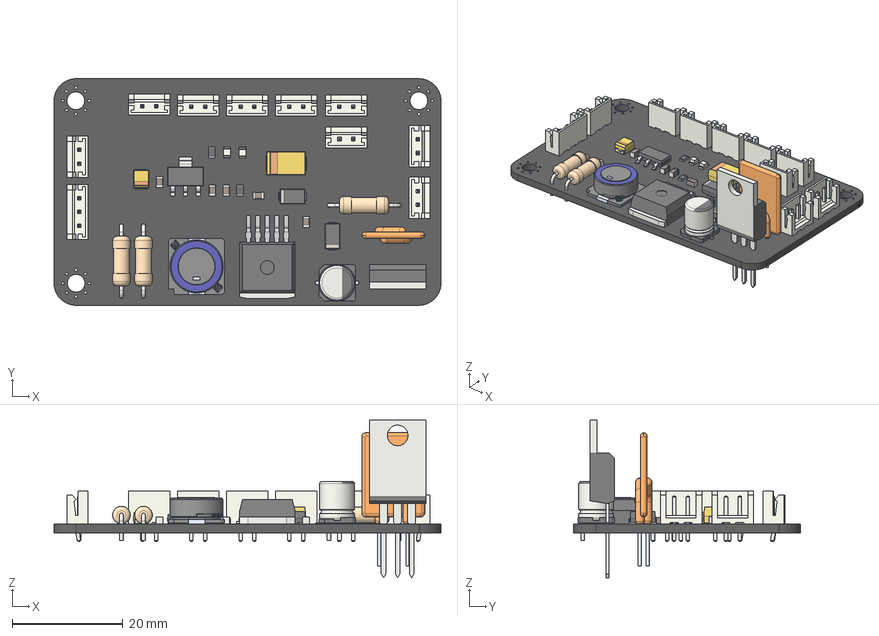
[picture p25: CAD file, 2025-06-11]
3D-MODEL/PRAMS 2.0 v3.step
70.0 x 41.0 x 28.5 mm
JST_B3B_EH_A
SLF10145T-102MR29-H
JST_B2B_EH_A x 9
C_0805_2012Metric_1 x 5
CP_EIA_3528_21_Kemet_B
TO-220-3_Vertical_1
D_SMA_1 x 2
R_0805_2012Metric_1 x 2
R_Axial_DIN0309_L90mm_D32mm_P1270mm_Horizontal x 3
RUEF300-1
CP_EIA_7343_31_Kemet_D
CP_Elec_63x77
CQ assembly
SOT_223
LED_0805_2012Metric_1 x 2
PRAMS 2.0_PCB

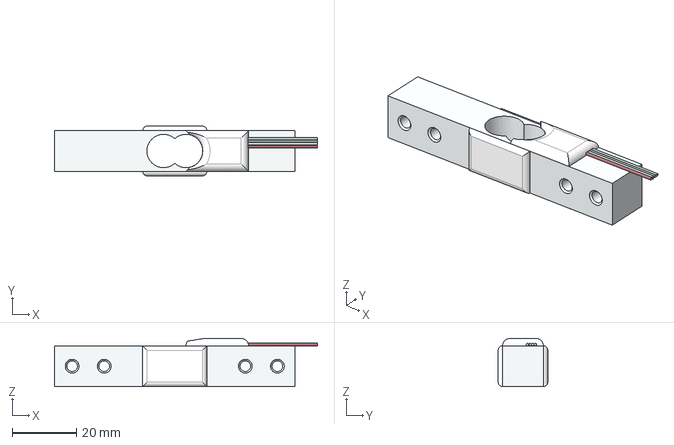
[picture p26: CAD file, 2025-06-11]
3D-MODEL/load sensor FHDA v1.step
82.0 x 15.5 x 15.0 mm

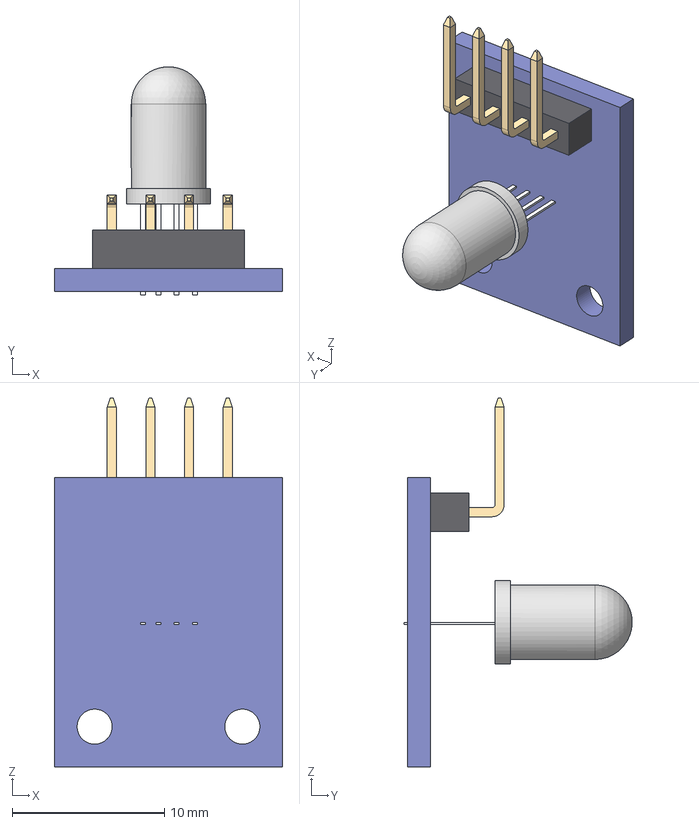
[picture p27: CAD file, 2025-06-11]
3D-MODEL/Led RGB for arduino v1.step
15.0 x 15.0 x 24.2 mm

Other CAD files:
3D-MODEL/FINAL PROJ v5.step

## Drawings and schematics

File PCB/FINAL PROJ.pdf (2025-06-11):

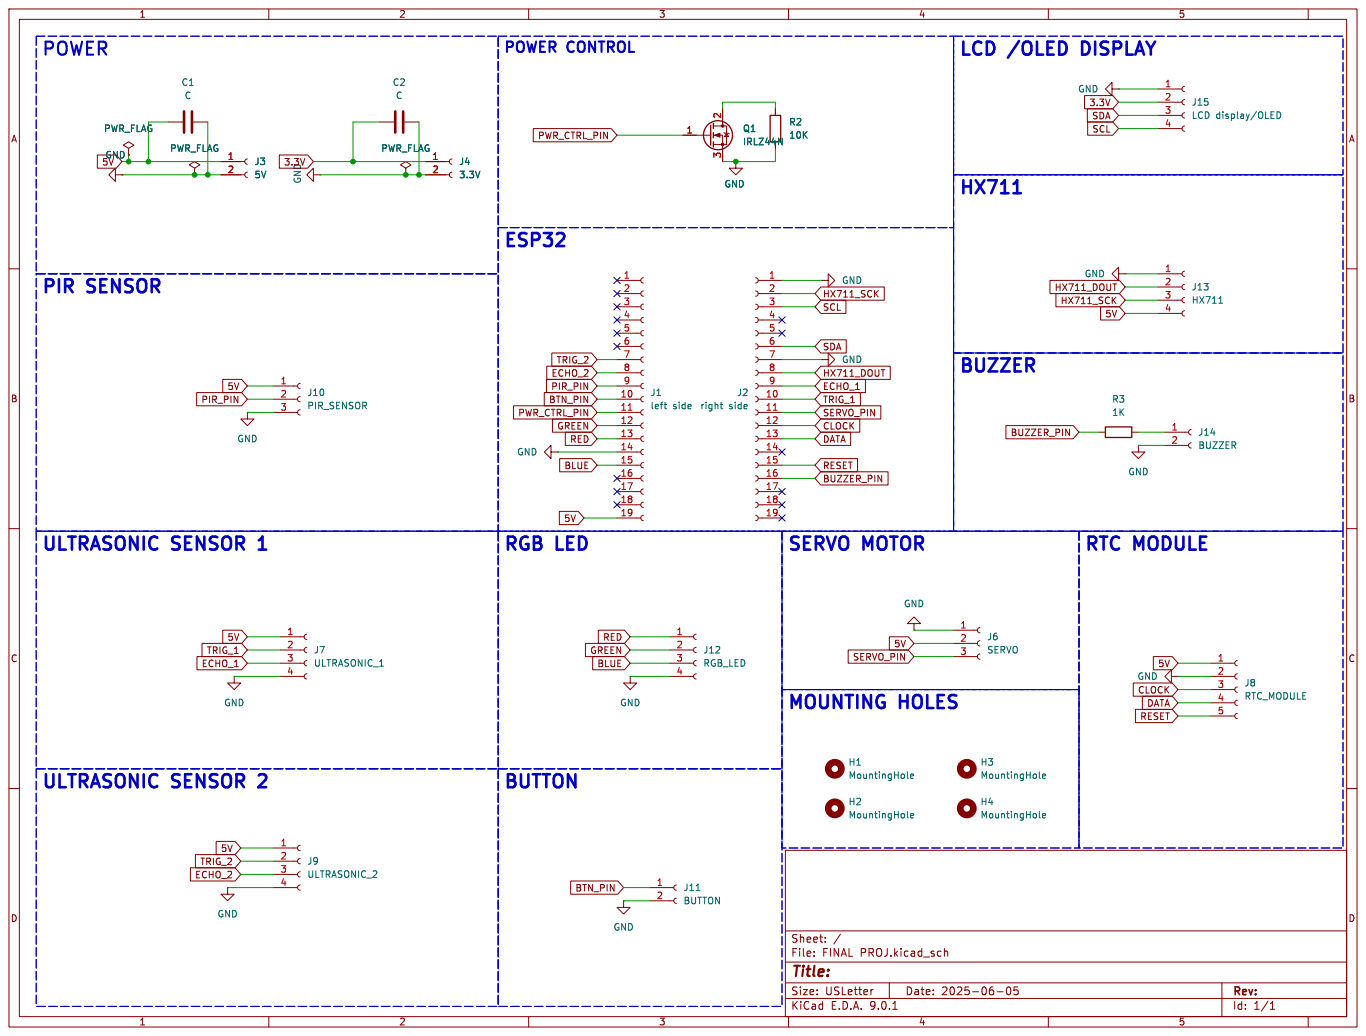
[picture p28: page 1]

LCD display/OLED GND
SCL SDA

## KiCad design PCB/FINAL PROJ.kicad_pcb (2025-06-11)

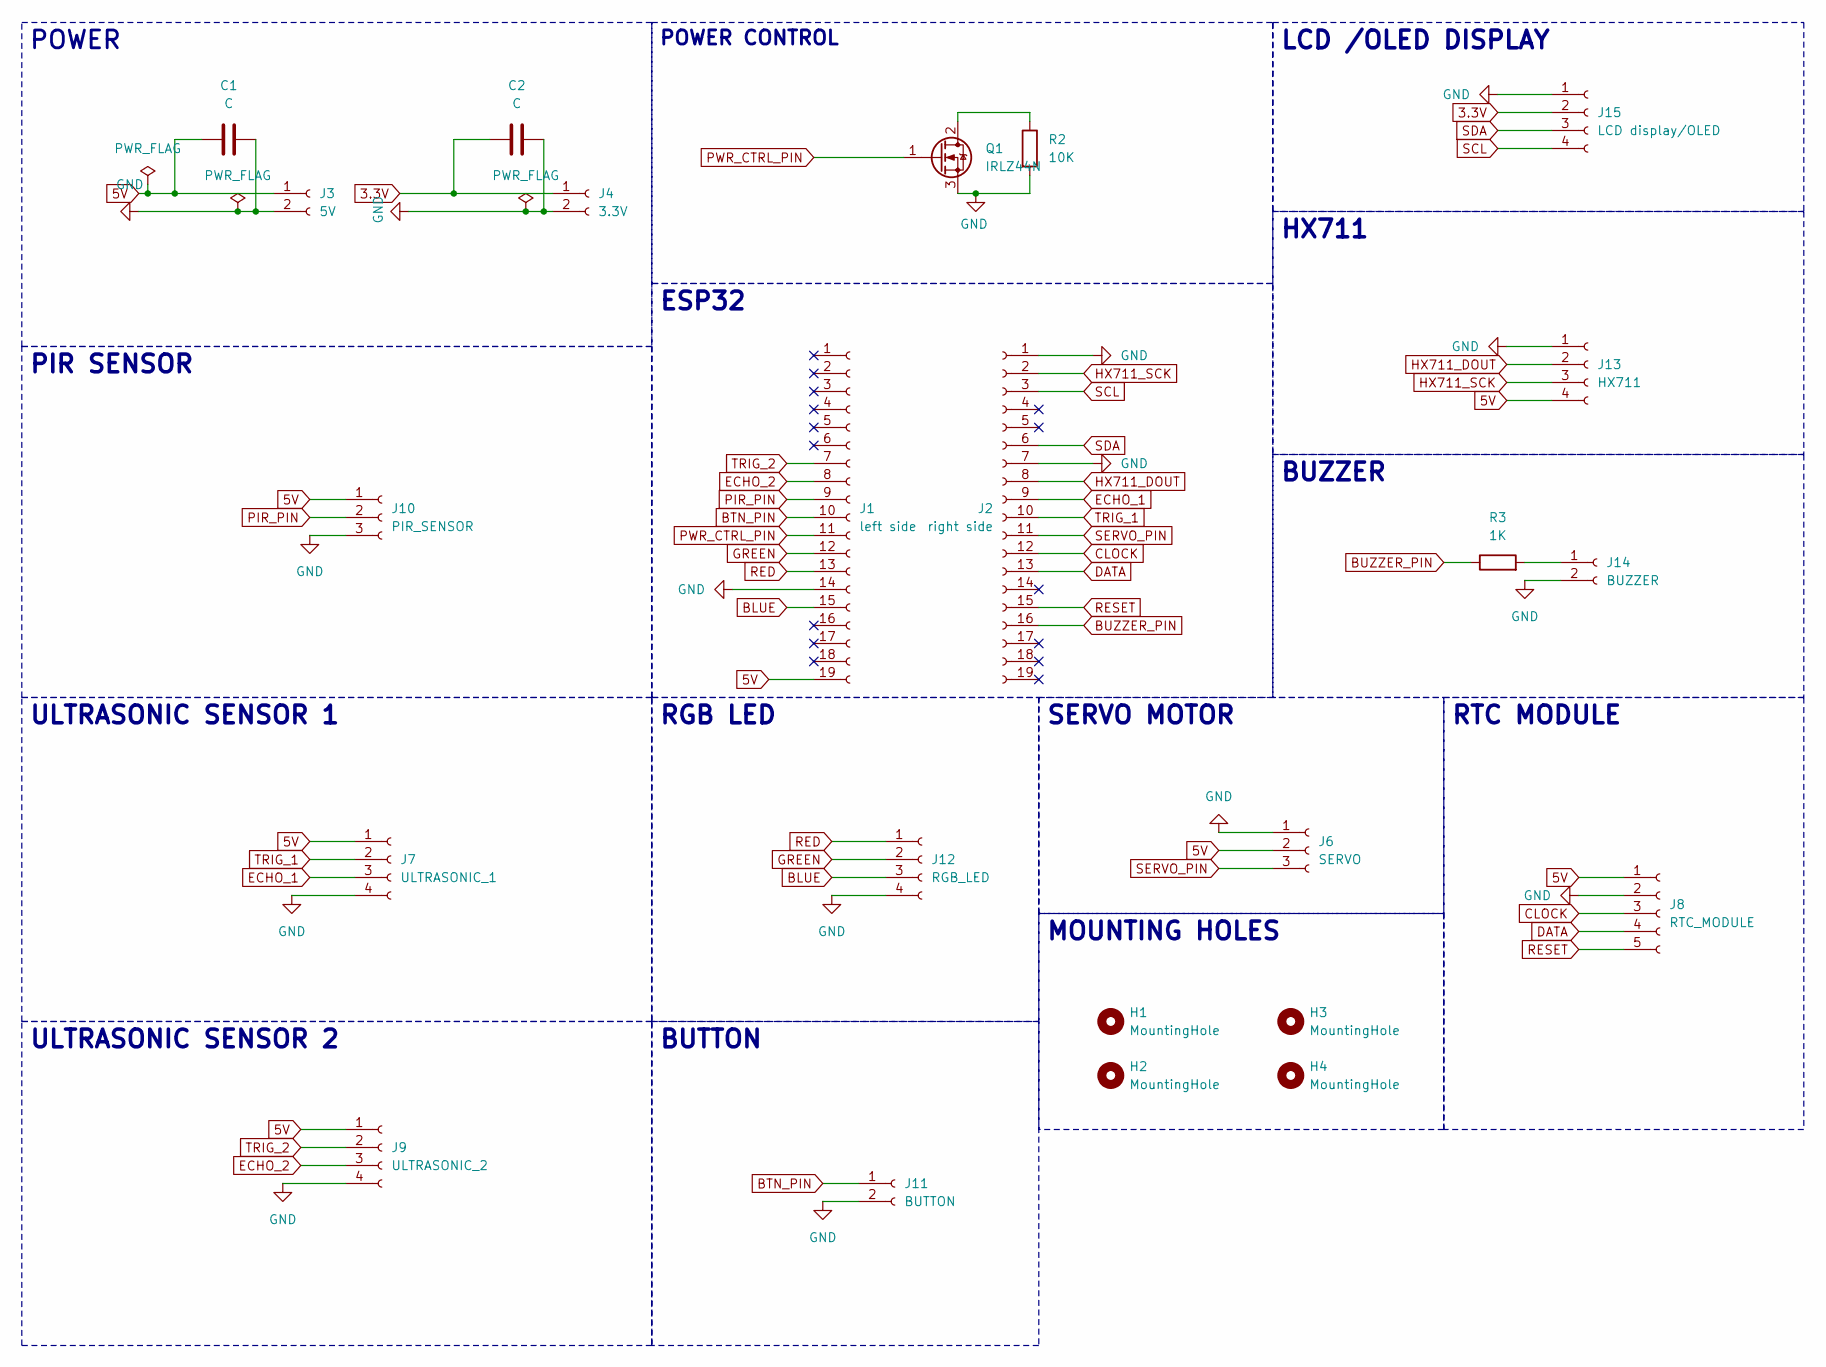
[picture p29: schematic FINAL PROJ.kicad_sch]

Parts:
C1, C2: C; C_Disc_D4.3mm_W1.9mm_P5.00mm
H1, H2, H3, H4: MountingHole; MountingHole_3.2mm_M3
J1: left side; PinSocket_1x19_P2.54mm_Vertical
J2: right side; PinSocket_1x19_P2.54mm_Vertical
J3: 5V; JST_EH_B2B-EH-A_1x02_P2.50mm_Vertical
J4: 3.3V; JST_EH_B2B-EH-A_1x02_P2.50mm_Vertical
J6: SERVO; JST_EH_B3B-EH-A_1x03_P2.50mm_Vertical
J7: ULTRASONIC_1; JST_EH_B4B-EH-A_1x04_P2.50mm_Vertical
J8: RTC_MODULE; PinSocket_1x05_P2.54mm_Vertical
J9: ULTRASONIC_2; JST_EH_B4B-EH-A_1x04_P2.50mm_Vertical
J10: PIR_SENSOR; JST_EH_B3B-EH-A_1x03_P2.50mm_Vertical
J11: BUTTON; JST_EH_B2B-EH-A_1x02_P2.50mm_Vertical
J12: RGB_LED; JST_EH_B4B-EH-A_1x04_P2.50mm_Vertical
J13: HX711; PinSocket_1x04_P2.54mm_Vertical
J14: BUZZER; JST_EH_B2B-EH-A_1x02_P2.50mm_Vertical
J15: LCD display/OLED; JST_EH_B4B-EH-A_1x04_P2.50mm_Vertical
Q1: IRLZ44N; TO-220-3_Vertical
R2: 10K; R_Axial_DIN0309_L9.0mm_D3.2mm_P12.70mm_Horizontal
R3: 1K; R_Axial_DIN0309_L9.0mm_D3.2mm_P12.70mm_Horizontal

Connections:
3.3V: C2.1, J4.1, J15.2
5V: C1.1, J1.19, J3.1, J6.2, J7.1, J8.1, J9.1, J10.1, J13.4
BLUE: J1.15, J12.3
BTN_PIN: J1.10, J11.1
BUZZER_PIN: J2.16, R3.1
CLOCK: J2.12, J8.3
DATA: J2.13, J8.4
ECHO_1: J2.9, J7.3
ECHO_2: J1.8, J9.3
GREEN: J1.12, J12.2
HX711_DOUT: J2.8, J13.2
HX711_SCK: J2.2, J13.3
unnamed: J14.1, R3.2
unnamed: Q1.2 (D), R2.1
PIR_PIN: J1.9, J10.2
PWR_CTRL_PIN: J1.11, Q1.1 (G)
RED: J1.13, J12.1
RESET: J2.15, J8.5
SCL: J2.3, J15.4
SDA: J2.6, J15.3
SERVO_PIN: J2.11, J6.3
TRIG_1: J2.10, J7.2
TRIG_2: J1.7, J9.2

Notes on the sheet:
HX711
PIR SENSOR
RGB LED
BUTTON
MOUNTING HOLES
ESP32
ULTRASONIC SENSOR 1
ULTRASONIC SENSOR 2
BUZZER
POWER CONTROL
RTC MODULE
POWER
LCD /OLED DISPLAY
SERVO MOTOR

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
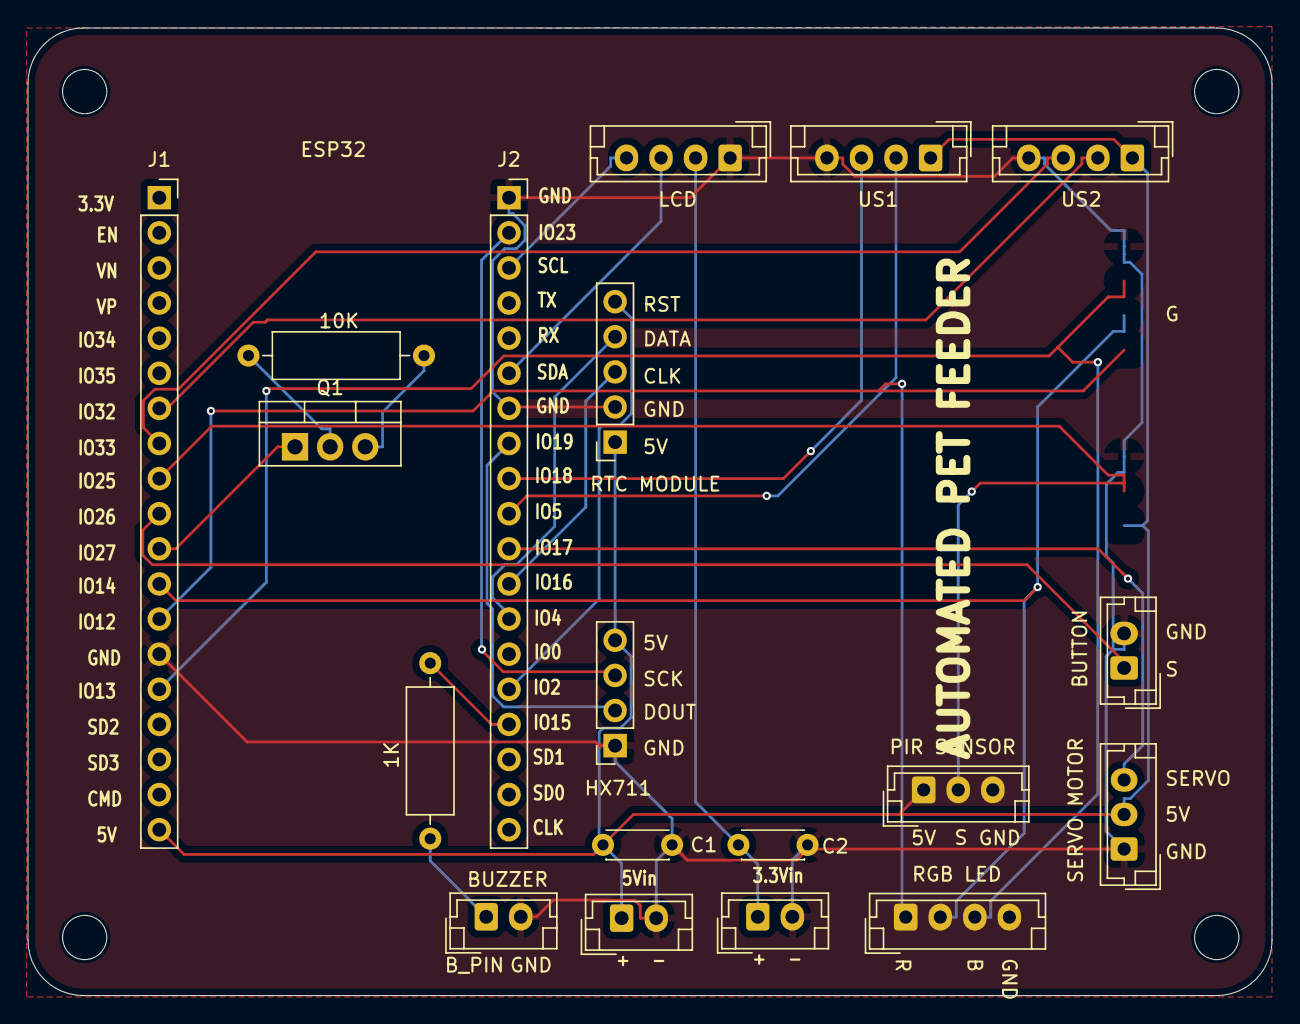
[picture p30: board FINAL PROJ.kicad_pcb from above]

Board: 2 copper layers, 90.0 x 70.0 mm, 23 parts (1 on the bottom side), 25 nets.

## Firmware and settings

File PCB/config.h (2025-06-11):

#ifndef CONFIG_H
#define CONFIG_H

#include <Arduino.h>
#include <RTClib.h>

// WiFi Configuration
#define WIFI_SSID "Your_WiFi_SSID"         // Replace with your WiFi name
#define WIFI_PASSWORD "Your_WiFi_Password" // Replace with your WiFi password
#define WIFI_RETRY_ATTEMPTS 20

// Server Configuration
#define PHP_SERVER_URL "http://192.168.1.100" // Replace with your computer's IP
#define DEVICE_NAME "PetFeeder Group 2"

// --- Pin Definitions ---
#define POWER_PIN 2
#define BUTTON1_PIN 15
#define BUTTON2_PIN 4
#define ULTRASONIC_TRIG_PIN 5
#define ULTRASONIC_ECHO_PIN 18
#define PIR_PIN 19
#define HX711_DOUT_PIN 16
#define HX711_SCK_PIN 17
#define RED_PIN 25
#define GREEN_PIN 26
#define BLUE_PIN 27
#define BUZZER_PIN 14
#define SERVO_PIN 13

// --- LCD Configuration ---
#define LCD_ADDRESS 0x27
#define LCD_COLUMNS 16
#define LCD_ROWS 2

// --- Scale Configuration ---
#define CALIBRATION_FACTOR -7050.0
#define WEIGHT_CHANGE_THRESHOLD 5.0

// --- Feeding Configuration ---
#define NORMAL_PORTION_SIZE 50.0
#define MAX_DAILY_FOOD 200.0
#define MIN_FEEDING_INTERVAL 300000
#define DISPENSE_TIME 3000

// --- Thresholds ---
#define EMPTY_BOWL_THRESHOLD 10.0
#define FULL_BOWL_THRESHOLD 100.0
#define ULTRASONIC_OFFSET 2.0
#define FOOD_FULL_DISTANCE 5.0
#define FOOD_HALF_DISTANCE 10.0

// --- Timing Intervals (milliseconds) ---
#define RTC_READ_INTERVAL 1000
#define WEIGHT_READ_INTERVAL 1000
#define PIR_READ_INTERVAL 500
#define DISTANCE_READ_INTERVAL 2000
#define DATA_SYNC_INTERVAL 30000
#define LCD_UPDATE_INTERVAL 1000
#define LOW_FOOD_BEEP_INTERVAL 60000
#define EMPTY_WARNING_INTERVAL 30000
#define DAILY_RESET_INTERVAL 86400000
#define AUTO_FEED_INTERVAL 14400

// --- Feeding Times (24-hour format) ---
#define FEEDING_TIME_1 8
#define FEEDING_TIME_2 12
#define FEEDING_TIME_3 18
#define FEEDING_TIME_4 22

// --- Buzzer Patterns ---
#define BUZZER_PATTERN_SINGLE 1
#define BUZZER_PATTERN_WARNING 2
#define BUZZER_PATTERN_DANGER 3
#define BUZZER_PATTERN_LOW_FOOD 5

// --- Buzzer Durations ---
#define BUZZER_SHORT_BEEP 100
#define BUZZER_MEDIUM_BEEP 300
#define BUZZER_LONG_BEEP 500
#define BUZZER_SHORT_PAUSE 100
#define BUZZER_MEDIUM_PAUSE 300
#define BUZZER_LONG_PAUSE 500

// --- RGB Colors ---
#define RGB_OFF "OFF"
#define RGB_RED "RED"
#define RGB_GREEN "GREEN"
#define RGB_BLUE "BLUE"
#define RGB_YELLOW "YELLOW"
#define RGB_PURPLE "PURPLE"
#define RGB_WHITE "WHITE"

// --- Food Level Constants ---
#define FOOD_LEVEL_FULL "FULL"
#define FOOD_LEVEL_HALF "HALF"
#define FOOD_LEVEL_EMPTY "EMPTY"
#define FOOD_LEVEL_UNKNOWN "UNKNOWN"

// --- Bowl Status Constants ---
#define BOWL_STATUS_EMPTY "EMPTY"
#define BOWL_STATUS_PARTIAL "PARTIAL"
#define BOWL_STATUS_FULL "FULL"
#define BOWL_STATUS_UNKNOWN "UNKNOWN"

// --- Feeding Status Constants ---
#define FEEDING_STATUS_READY "READY"
#define FEEDING_STATUS_WAIT "WAIT"
#define FEEDING_STATUS_BOWL_FULL "BOWL_FULL"
#define FEEDING_STATUS_DAILY_LIMIT "DAILY_LIMIT"

// --- Default Settings ---
#define DEFAULT_REFILL_MODE false
#define DEFAULT_AUTO_FEEDING_ENABLED true
#define DEFAULT_SCHEDULED_FEEDING_MODE false
#define DEFAULT_WEIGHT_BASED_FEEDING true

// --- Button Configuration ---
#define DEBOUNCE_DELAY 50

// --- JSON Buffer Sizes ---
#define JSON_BUFFER_SIZE_SMALL 512
#define JSON_BUFFER_SIZE_MEDIUM 1024
#define JSON_BUFFER_SIZE_LARGE 2048

// --- Array Size Macro ---
#define ARRAY_SIZE(arr) (sizeof(arr) / sizeof(arr[0]))

// Struct Definitions
struct SystemState
{
  bool initialized = false;
  bool rtcReady = false;
  bool backendConnected = false;
  bool powerOn = false;
  bool refillMode = DEFAULT_REFILL_MODE;
  bool dispensing = false;
  bool autoFeedingEnabled = DEFAULT_AUTO_FEEDING_ENABLED;
  bool scheduledFeedingMode = DEFAULT_SCHEDULED_FEEDING_MODE;
  bool weightBasedFeeding = DEFAULT_WEIGHT_BASED_FEEDING;
  bool animalDetected = false;
  bool bowlEmpty = false;
  bool bowlFull = false;
};

struct ButtonState
{
  bool button1 = false;
  bool button2 = false;
  bool lastButton1 = false;
  bool lastButton2 = false;
};

struct SensorData
{
  float distance = 0.0;
  float distanceInches = 0.0;
  float weight = 0.0;
  float previousWeight = 0.0;
  float weightDifference = 0.0;
  float totalFoodDispensed = 0.0;
  float dailyFoodDispensed = 0.0;
  String foodLevel = FOOD_LEVEL_UNKNOWN;
  String bowlStatus = BOWL_STATUS_UNKNOWN;
  String feedingStatus = FEEDING_STATUS_READY;
};

struct Timing
{
  unsigned long lastButton1Press = 0;
  unsigned long lastButton2Press = 0;
  unsigned long dispenseStartTime = 0;
  unsigned long lastDistanceRead = 0;
  unsigned long lastPIRRead = 0;
  unsigned long lastWeightRead = 0;
  unsigned long lastWeightChange = 0;
  unsigned long lastDailyReset = 0;
  unsigned long lastFeedingTime = 0;
  unsigned long lastRTCRead = 0;
  unsigned long lastDataSync = 0;
  unsigned long lastLCDUpdate = 0;
  unsigned long lastLowFoodBeep = 0;
};

struct TimeData
{
  DateTime lastAutoFeedTime;
  DateTime nextScheduledFeed;
  String currentTimeString = "";
  String nextFeedTimeString = "";
};

struct Endpoints
{
  String hostName = String(PHP_SERVER_URL);
  String feedPath = "/feed.php";
  String statusPath = "/status.php";
  String sensorPath = "/collect_sensor_data.php";
  String commandPath = "/remote_commands.php";
};

#endif // CONFIG_H

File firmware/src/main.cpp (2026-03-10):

#include <Arduino.h>
#include "config.h"
#include "globals.h"
#include "system_init.h"
#include "sensor_manager.h"
#include "feeding_control.h"
#include "button_handler.h"
#include "display_manager.h"
#include "time_manager.h"
#include "network_manager.h"
#include "ble_manager.h"
#include "load_cell.h"

// ============================================================================
// Setup
// ============================================================================
void setup() {
    Serial.begin(115200);
    Serial.printf("\n=== Pet Feeder v%s ===\n", FIRMWARE_VERSION);

    unsigned long setupStart = millis();
    const unsigned long SETUP_TIMEOUT = 30000;

    // Core hardware init
    systemStart();

    // Load cell
    if (!scale.is_ready()) {
        setupLoadCell();
    }

    // Buttons
    initButtons();

    // BLE for mobile app
    initBLE();

    // Quick database connectivity test (skip if WiFi failed or timeout close)
    if (WiFi.status() == WL_CONNECTED &&
        millis() - setupStart < SETUP_TIMEOUT - 5000) {
        lcd.clear();
        lcd.setCursor(0, 0);
        lcd.print("DB Test...");
        bool dbOk = sendToDatabase();
        lcd.setCursor(0, 1);
        lcd.print(dbOk ? "Connected" : "Skipped");
        delay(500);
    }

    // Ready
    lcd.clear();
    lcd.setCursor(0, 0);
    lcd.print("System Ready!");
    lcd.setCursor(0, 1);
    lcd.print(WiFi.status() == WL_CONNECTED ? "Online Mode" : "Offline Mode");
    delay(1000);
    lcd.clear();

    feederSystem.initialized = true;
    Serial.printf("Setup done in %lu ms\n", millis() - setupStart);
}

// ============================================================================
// Main Loop
// ============================================================================
void loop() {
    if (!feederSystem.initialized) {
        delay(100);
        return;
    }

    unsigned long now = millis();

    // 1. Buttons first — manual override takes priority
    handleButtons();

    // 2. Feeding state machine (dispense timing, auto-feed check)
    if (!feederSystem.dispensing) {
        handleFeeding();
    }

    // 3. RTC & scheduled feeding
    if (feederSystem.rtcReady && !feederSystem.dispensing &&
        now - timing.lastRTCRead >= RTC_READ_INTERVAL) {
        RtcDateTime rtcNow = rtc.GetDateTime();

        String ts = formatTime(rtcNow);
        strncpy(timeData.currentTimeString, ts.c_str(),
                sizeof(timeData.currentTimeString) - 1);

        String nf = formatTime(timeData.nextScheduledFeed);
        strncpy(timeData.nextFeedTimeString, nf.c_str(),
                sizeof(timeData.nextFeedTimeString) - 1);

        if (shouldAutoFeed(rtcNow) && !feederSystem.dispensing) {
            Serial.println(">>> Auto-feed triggered");
            performAutoFeed();
        }
        timing.lastRTCRead = now;
    }

    // 4. Sensors
    handleSensors();

    if (now - timing.lastWeightRead >= WEIGHT_READ_INTERVAL) {
        updateBowlWeight();
        timing.lastWeightRead = now;
    }

    // 5. Check if dispense cycle finished
    checkFeedingComplete();

    // 6. BLE communication with mobile app
    handleBLE();

    // 7. Cloud sync
    handleBackendCommunication();

    // 8. LCD
    if (now - timing.lastLCDUpdate >= LCD_UPDATE_INTERVAL) {
        updateLCD();
        timing.lastLCDUpdate = now;
    }

    // 9. Midnight reset
    resetDailyCounters();

    // 10. Periodic status dump
    if (now - timing.lastStatusPrint >= STATUS_PRINT_INTERVAL) {
        Serial.printf("\n=== STATUS ===\n");
        Serial.printf("WiFi: %s (%d dBm)\n",
                      WiFi.status() == WL_CONNECTED ? "OK" : "OFF", WiFi.RSSI());
        Serial.printf("MQTT: %s | BLE: %s\n",
                      feederSystem.mqttConnected ? "OK" : "OFF",
                      feederSystem.bleConnected  ? "OK" : "OFF");
        Serial.printf("Heap: %d B | Uptime: %lu s\n",
                      ESP.getFreeHeap(), now / 1000);
        Serial.println("==============\n");
        timing.lastStatusPrint = now;
    }
}

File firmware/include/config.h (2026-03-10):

#ifndef CONFIG_H
#define CONFIG_H

#include <Arduino.h>
#include <ThreeWire.h>
#include <RtcDS1302.h>

// Load secrets from external file (never committed to git)
#include "secrets.h"

// ============================================================================
// WiFi Configuration
// ============================================================================
#define WIFI_SSID             ENV_WIFI_SSID
#define WIFI_PASSWORD         ENV_WIFI_PASSWORD
#define WIFI_RETRY_ATTEMPTS   20
#define WIFI_RETRY_DELAY_MS   500

// ============================================================================
// Device Configuration
// ============================================================================
#define DEVICE_NAME           "PetFeeder_001"
#define FIRMWARE_VERSION      "2.0.0"

// ============================================================================
// Pin Definitions (matches PCB v2 layout)
// ============================================================================
#define POWER_PIN             27
#define BUTTON1_PIN           15    // Refill mode toggle
#define BUTTON2_PIN           0     // Manual feed
#define ULTRASONIC_TRIG_PIN   32
#define ULTRASONIC_ECHO_PIN   33
#define PIR_PIN               25
#define HX711_DOUT_PIN        5
#define HX711_SCK_PIN         23
#define RED_PIN               13
#define GREEN_PIN             12
#define BLUE_PIN              14
#define BUZZER_PIN            26
#define SERVO_PIN             4

// DS1302 RTC Module Pins
#define RTC_IO                16
#define RTC_SCLK              17
#define RTC_CE                2

// ============================================================================
// LCD Configuration
// ============================================================================
#define LCD_ADDRESS           0x27
#define LCD_COLUMNS           16
#define LCD_ROWS              2

// ============================================================================
// Timing Intervals (milliseconds)
// ============================================================================
#define ULTRASONIC_READ_INTERVAL  200
#define WEIGHT_READ_INTERVAL      500
#define RTC_READ_INTERVAL         5000
#define LCD_UPDATE_INTERVAL       400
#define DATA_SYNC_INTERVAL        30000
#define DISPENSE_TIME             1000
#define MIN_FEEDING_INTERVAL      300000  // 5 minutes
#define PIR_TIMEOUT               30000   // 30 seconds
#define DEBOUNCE_DELAY            50
#define MQTT_RECONNECT_INTERVAL   10000
#define STATUS_PRINT_INTERVAL     30000

// ============================================================================
// Sensor Thresholds
// ============================================================================
#define FOOD_FULL_DISTANCE    9.0     // cm — container nearly full
#define FOOD_HALF_DISTANCE    13.5    // cm — roughly half
#define FOOD_EMPTY_DISTANCE   18.0    // cm — nearly empty
#define EMPTY_BOWL_THRESHOLD  10.0    // grams
#define FULL_BOWL_THRESHOLD   200.0   // grams
#define SCALE_READINGS        3

// ============================================================================
// Load Cell Calibration
// ============================================================================
#define CALIBRATION_FACTOR    49400   // Adjust during calibration

// ============================================================================
// Food Management
// ============================================================================
#define FOOD_PORTION_GRAMS    25.0
#define MAX_DAILY_FOOD        200.0   // grams per day

// Feeding Times (minutes from midnight)
#define FEEDING_TIME_1        480     // 08:00 AM
#define FEEDING_TIME_2        720     // 12:00 PM
#define FEEDING_TIME_3        1080    // 06:00 PM
#define FEEDING_TIME_4        1320    // 10:00 PM

// ============================================================================
// Azure IoT Hub / MQTT
// ============================================================================
#define MQTT_SERVER           ENV_MQTT_SERVER
#define MQTT_PORT             ENV_MQTT_PORT
#define DEVICE_ID             ENV_DEVICE_ID
#define SAS_TOKEN             ENV_SAS_TOKEN
#define MQTT_USERNAME         ENV_MQTT_USERNAME
#define DATABASE_ENDPOINT     ENV_DATABASE_ENDPOINT
#define MQTT_BUFFER_SIZE      1024

// ============================================================================
// BLE Configuration (for mobile app)
// ============================================================================
#define BLE_DEVICE_NAME       "PetFeeder"
#define BLE_SERVICE_UUID      "4fafc201-1fb5-459e-8fcc-c5c9c331914b"
#define BLE_CHAR_CMD_UUID     "beb5483e-36e1-4688-b7f5-ea07361b26a8"
#define BLE_CHAR_STATUS_UUID  "a3c87500-8ed3-4bdf-8a39-a01bebede295"
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

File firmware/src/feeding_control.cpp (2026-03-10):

#include "feeding_control.h"

void handleFeeding() {
    // Nothing to do if not currently dispensing
    // Auto-feed is triggered from main loop via shouldAutoFeed()
}

void performAutoFeed() {
    if (canDispenseFood() && !feederSystem.dispensing) {
        Serial.println("Auto dispensing...");
        myServo.write(180);
        feederSystem.dispensing = true;
        timing.dispenseStartTime = millis();
        recordFoodDispensing("auto");
        buzzerBeepWithLED(BUZZER_PATTERN_SINGLE, BUZZER_MEDIUM_BEEP, 0, RGB_PURPLE);
        setRGBColor(RGB_PURPLE);
    }
}

void performManualFeed() {
    if (canDispenseFood() && !feederSystem.dispensing) {
        Serial.println("Manual dispensing...");
        myServo.write(180);
        feederSystem.dispensing = true;
        buttons.manualFeedInProgress = true;
        timing.dispenseStartTime = millis();
        recordFoodDispensing("manual");
        buzzerBeepWithLED(BUZZER_PATTERN_SINGLE, BUZZER_MEDIUM_BEEP, 0, RGB_PURPLE);
        setRGBColor(RGB_PURPLE);
    }
}

bool canDispenseFood() {
    unsigned long now = millis();

    if (sensors.dailyFoodDispensed >= MAX_DAILY_FOOD)
        return false;

    if (feederSystem.bowlFull || strcmp(sensors.bowlStatus, BOWL_STATUS_FULL) == 0)
        return false;

    if (now - timing.lastFeedingTime < MIN_FEEDING_INTERVAL && timing.lastFeedingTime != 0)
        return false;

    if (strcmp(sensors.foodLevel, FOOD_LEVEL_EMPTY) == 0)
        return false;

    return true;
}

void checkFeedingComplete() {
    if (feederSystem.dispensing &&
        millis() - timing.dispenseStartTime >= DISPENSE_TIME) {
        myServo.write(0);
        feederSystem.dispensing = false;
        buttons.manualFeedInProgress = false;
        buzzerBeepWithLED(BUZZER_PATTERN_WARNING, BUZZER_MEDIUM_BEEP,
                          BUZZER_MEDIUM_PAUSE, RGB_PURPLE);
        setRGBColor(sensors.foodLevel);
        Serial.println("Dispensing complete");
    }
}

void recordFoodDispensing(const char* feedingType) {
    float dispensed = FOOD_PORTION_GRAMS;
    sensors.dailyFoodDispensed += dispensed;
    sensors.totalFoodDispensed += dispensed;
    timing.lastFeedingTime = millis();

    if (feederSystem.rtcReady) {
        RtcDateTime now = rtc.GetDateTime();
        timeData.lastAutoFeedTime = now;
        timeData.nextScheduledFeed = getNextScheduledFeedTime(now);
        String ts = formatDateTime(now);
        sendFeedingDataToAzure(feedingType, dispensed, ts.c_str());
    }
}

const char* getFeedingStatus() {
    if (sensors.dailyFoodDispensed >= MAX_DAILY_FOOD)
        return "Daily limit reached";
    if (feederSystem.bowlFull || strcmp(sensors.bowlStatus, BOWL_STATUS_FULL) == 0)
        return "Bowl full";
    if (millis() - timing.lastFeedingTime < MIN_FEEDING_INTERVAL && timing.lastFeedingTime != 0)
        return "Too soon";
    if (strcmp(sensors.foodLevel, FOOD_LEVEL_EMPTY) == 0)
        return "No food";
    return "Ready to feed";
}

void resetDailyCounters() {
    if (!feederSystem.rtcReady) return;

    RtcDateTime now = rtc.GetDateTime();
    static uint8_t lastDay = 0;

    if (lastDay != now.Day()) {
        sensors.dailyFoodDispensed = 0.0;
        lastDay = now.Day();
        Serial.println("Daily counters reset");
    }
}

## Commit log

2025-06-11 feat(3d model): Components for 3d model were added
    [DC Power Jack 5.5mm x 2.1mm v1.step, FINAL PROJ v5.step, Led RGB for arduino v1.step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]
2025-06-11 feat(hardware-code): Code for the hardware were added
    [DC Power Jack 5.5mm x 2.1mm v1.step, FINAL PROJ v5.step, Led RGB for arduino v1.step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]
2025-06-11 feat(pcb): Pcb design for breakout board was added
    [FINAL PROJ.kicad_pcb, FINAL PROJ.kicad_sch, FINAL PROJ.step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]
2025-06-11 Added System Power consumption and its diagram
    [PetFeeder_Current_Consumption (1).xlsx]
2026-03-10 Add core functionality for pet feeder system
    - Implement main application logic in main.cpp, including setup and loop functions.
    - Create network_manager.cpp for handling MQTT setup, connection, and backend communication.
    - Develop sensor_manager.cpp to manage sensor readings and status updates.
    - Initialize system components in system_init.cpp, including WiFi and RTC setup.
    - Implement time management functions in time_manager.cpp for scheduling feeds and formatting timestamps.
    - Add load cell calibration test in test_calibration.cpp for determining calibration factor.
    [power-consumption.xlsx]
